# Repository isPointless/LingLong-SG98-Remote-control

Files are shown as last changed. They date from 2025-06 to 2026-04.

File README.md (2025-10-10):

# LingLong SG98 Remote control
A remote control PCB & software to control a grinder with a servo motor.
Currently being built for Linglong SG98 using RT and JMC servo drive.

#### How to use
Aquire a PCB (order through JLCPCB with the provided files or buy a readymade one). and wire it up correctly.
Install Visual Studio code, install the PlatformIO extension. Clone this repo.

Make sure to (un)comment the proper drive type in definitions.
Uploading to ESP32 through USB-C. Make sure +24v is not present. If necessary short press EN while holding BOOT0 button for uploading.
If flash error in final install, plugging in the USB C shortly after pressing "Upload" will make it work.

#### BOM
- ESP32 PCB board + 90 degree 2.54 pins
- 1.69" round corner SPI color display + 2.54 female header
- 19mm ultra short throw momentary button with 3-5V LED.
- M12 4 pin female connector
- KCD1 SPST switch
- 3D printed box, including 4xM3x5Wx4L heat inserts and 2x m3*8 countersunk screw and m3*6 non-countersunk screw.
- A knob for the rotary encoder to your choosing.

-

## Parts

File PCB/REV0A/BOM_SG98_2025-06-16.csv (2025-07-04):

Designator | Footprint | Quantity | Manufacturer Part | Manufacturer | Supplier | Supplier Part | Price
C14,C15 | C0603 | 2 | CL05B104KO5NNNC | SAMSUNG | LCSC | C21122 | 0.004
SW_GND_LED-_3V3 | HDR-TH_4P-P2.54-V-M_1 | 1 |  |  | LCSC
R27 | R1206 | 1 | 1206W4F1000T5E | UNI-ROYAL(厚声) | LCSC | C17901 | 0.003
R3,R4 | R0603 | 2 | 0603WAF6800T5E | UNI-ROYAL(厚声) | LCSC | C23228 | 0.001
C11 | C0603 | 1 |  |  | LCSC | C14663 | 0.003
C12,C19 | C0603 | 2 | CL10C100JB8NNNC | SAMSUNG(三星) | LCSC | C1634 | 0.005
C2,C10 | C1206 | 2 | CL31A106KBHNNNE | SAMSUNG(三星) | LCSC | C13585 | 0.034
R24,R26 | R0603 | 2 | 0603WAF1004T5E | UNI-ROYAL(厚声) | LCSC | C22935 | 0.001
EX_SPI | HDR-TH_6P-P2.54-V-M-A | 1 |  |  | LCSC
EN,GPIO0 | SW-SMD_L3.9-W3.0-P4.45 | 2 | TS-1088-AR02016 | XUNPU(讯普) | LCSC | C720477 | 0.043
R20 | R0603 | 1 | 0402WGF2702TCE | UniOhm | LCSC | C22967 | 0.001
RS485 | TERMINAL_BLOCK_3P_5 | 1
UART | HDR-TH_3P-P2.54-V-M-3 | 1
R6,R7,R16,R25 | R0603 | 4 | 0603WAF2702T5E | UNI-ROYAL(厚声) | LCSC | C22967 | 0.001
R2,R8,R13,R17,R18,R21 | R0603 | 6 | 0603WAF1002T5E | UNI-ROYAL(厚声) | LCSC | C25804 | 0.001
GPIO2 | LED0805-R-RD | 1 | KT-0805黄灯 | KENTO | LCSC | C2296 | 0.012
L1 | SM/L_LPS6235-153MRC | 1 | ? | LPS6235-153MRC | LCSC | C3033031 | 1.562
24V-IN | TERMINALBLOCK:TERMINALBLOCK_BORNIER-2_P5.08MM | 1 |  |  | LCSC
C1,C7,C8,C13,C16,C17,C18,C20,C21,C22 | C0603 | 10 | CC0603KRX7R9BB104 | YAGEO(国巨) | LCSC | C14663 | 0.003
C3,C4,C5 | C0603 | 3 | CL10A106KP8NNNC | SAMSUNG(三星) | LCSC | C19702 | 0.006
C6,C9 | C0603 | 2 | CL10A105KB8NNNC | SAMSUNG(三星) | LCSC | C15849 | 0.005
EX_I2C | HDR-TH_4P-P2.54-V-M_1 | 1 |  |  | LCSC
D2 | SOT-23-6_L2.9-W1.6-P0.95-LS2.8-BR | 1 | USBLC6-2SC6 | STMicroelectronics | LCSC | C7519 | 0.11
D4 | SOT-23(SOT-23-3) | 1 |  | ElecSuper |  | C5180294 | 0.031
F1,F2 | F1812 | 2 | SMD1812P050TF | RUILON(瑞隆源) | LCSC | C12558 | 0.09
L3 | FILTER-SMD_4P-L9.0-W6.0_B82790 | 1 | B82793S0513N201 | TDK | LCSC | C97047 | 0.575
POW1 | LED0603-RD | 1 | KT-0603R | KENTO | LCSC | C2286 | 0.006
Q1 | SOT-23-3_L2.9-W1.3-P1.90-LS2.4-BR | 1 | SS8050(RANGE:200-350) | CJ(江苏长电/长晶) | LCSC | C2150 | 0.013
R1 | R0603 | 1 | 0603WAF3162T5E | UNI-ROYAL(厚声) | LCSC | C25967 | 0.001
R5 | R0603 | 1 | 0603WAF1003T5E | UNI-ROYAL(厚声) | LCSC | C25803 | 0.001
R9,R10,R23 | R0603 | 3 | 0603WAF1001T5E | UNI-ROYAL(厚声) | LCSC | C21190 | 0.001
R11,R12 | R0603 | 2 | 0603WAF5101T5E | UNI-ROYAL(厚声) | LCSC | C23186 | 0.001
R15 | R0603 | 1 | 0603WAF5102T5E | UNI-ROYAL(厚声) | LCSC | C23196 | 0.001
R19,R22 | R0603 | 2 | 0603WAF4700T5E | UNI-ROYAL(厚声) | LCSC | C23179 | 0.001
R14 | R1206 | 1 | 1206W4F1200T5E | UNI-ROYAL(厚声) | LCSC | C17909 | 0.003
SPI_DISPLAY | HDR_TH_8P | 1
SW3 | SW-TH_EC11E15244G1 | 1 | EC11E15244G1 | ALPS Electric | LCSC | C370970 | 2.1
U1 | XDFN-4_L1.0-W1.0-P0.65-BL-EP | 1 | NCP167BMX330TBG | onsemi(安森美) | LCSC | C892227 | 0.428
U2 | MSOP-8 | 1 | MCP16311-E/MS | MICROCHIP | LCSC | C627024 | 1.402
U6 | SOIC-8 | 1 | MAX3485ESA+ | Maxim Integrated | LCSC | C18148 | 1.573
U18 | WIFIM-SMD_ESP32-S3-WROOM-1-N8-NO-VIAS | 1 | ESP32-S3-WROOM-1-N8 | ESPRESSIF(乐鑫) | LCSC | C2913198 | 5.05
USBC1 | USB-C_SMD-TYPE-C-31-M-12 | 1 | TYPE-C-31-M-12 | 韩国韩荣 | LCSC | C165948 | 0.173

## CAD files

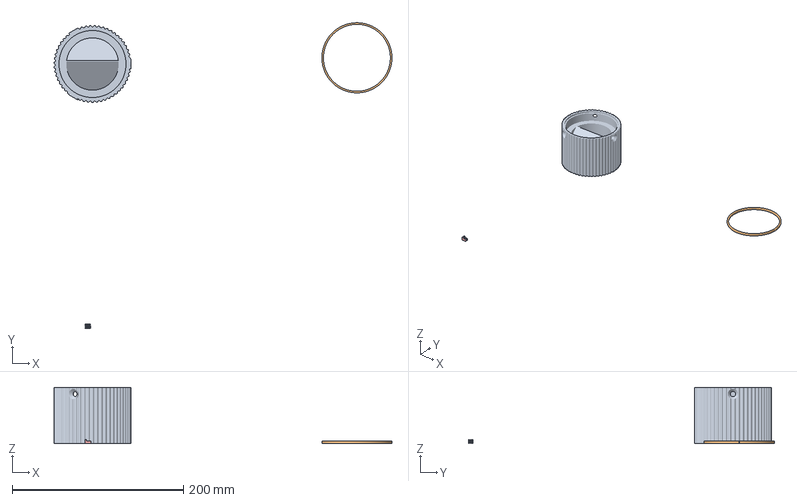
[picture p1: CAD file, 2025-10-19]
3DP parts/Hopper+V2+3mf.3mf
395.0 x 357.1 x 66.0 mm
Hopper V2.stl
Dial indicator V3 Ring.stl
Dial indicator V3.stl x 3

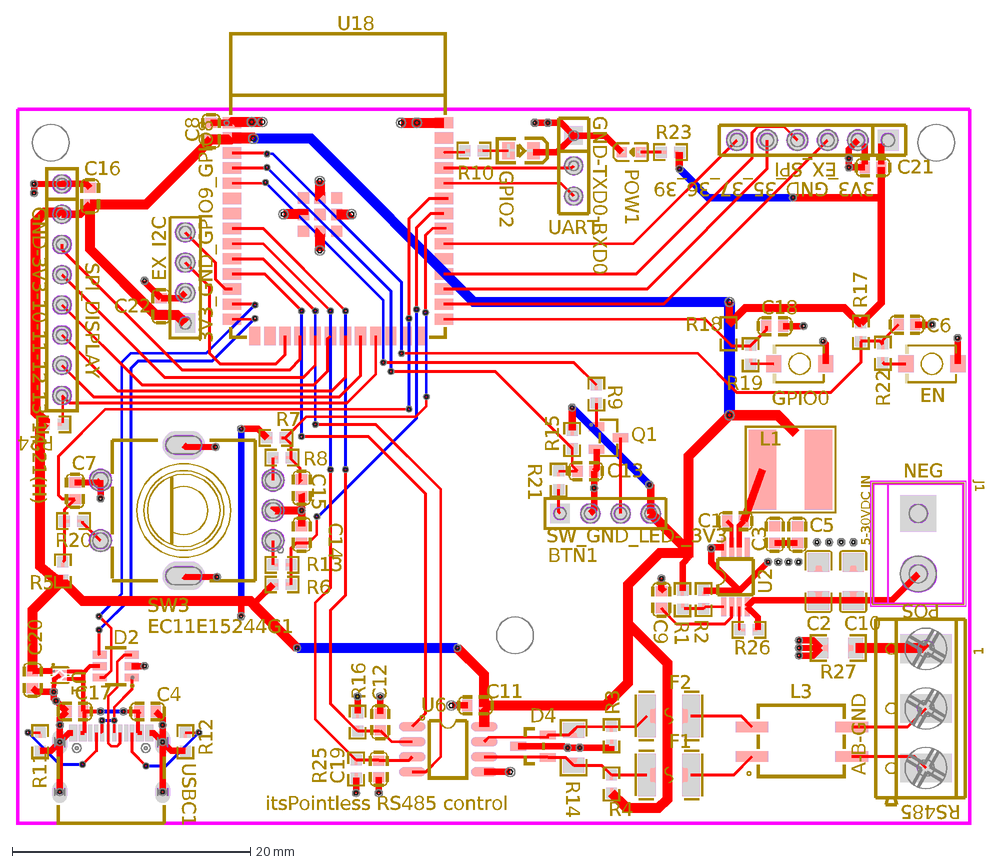
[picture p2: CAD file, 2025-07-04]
PCB/REV0A/PCB_SG98_2025-06-18.dxf
3V3_GND_35_37_36_39
GND-TXD0-RXD0
POS
NEG
A-B-GND
RS485
GND-3V3-10-11-12-13-14-21(H)
itsPointless RS485 control
BTN1
3V3_GND_GPIO9_GPIO8
C14
C15
SW_GND_LED-_3V3
R27
R3
R4
C11
C12
C19
C2
C10
R24
R26
EX_SPI
EN
GPIO0
R20
1
UART
R6
R7
R8
R13
GPIO2
L1
J1
5-30VDC IN
C1
C3
C4
C5
C6
C7
C8
C9
C13
C16
C17
C18
C20
C21
C22
EX_I2C
D2
D4
F1
F2
L3
POW1
Q1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

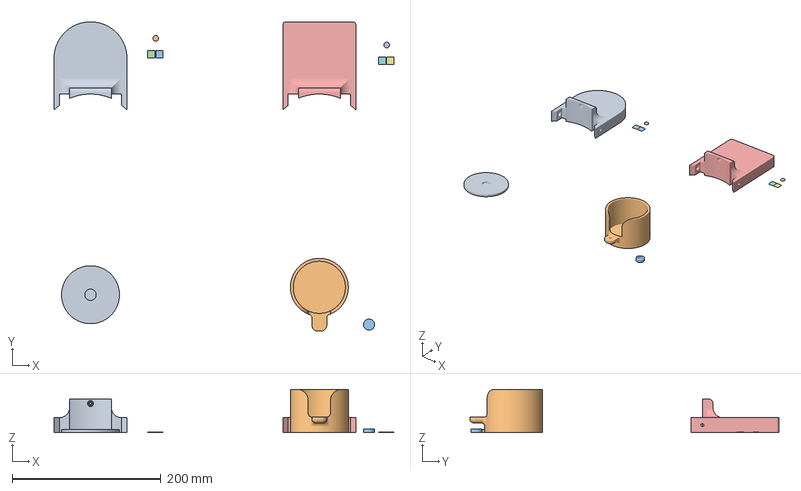
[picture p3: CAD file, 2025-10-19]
3DP parts/Cup+holder+V2++3mf.3mf
456.4 x 415.3 x 58.0 mm
Cup Holder V2 Base.stl
Anti scratch 2.stl x 2
Anti scratch.stl x 4
Cup Holder V2 Base rectangular.stl
Magnet_plate.stl
PF_Holder.stl
PF_Holder_adj_srew.stl

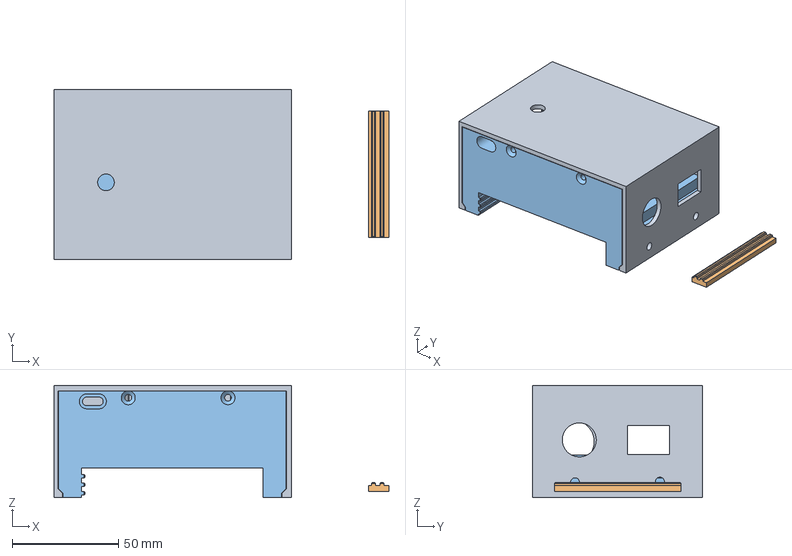
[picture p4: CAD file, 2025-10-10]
3DP parts/LL SideBox V5 RT v0.3mf
157.9 x 80.0 x 52.8 mm
Clamp

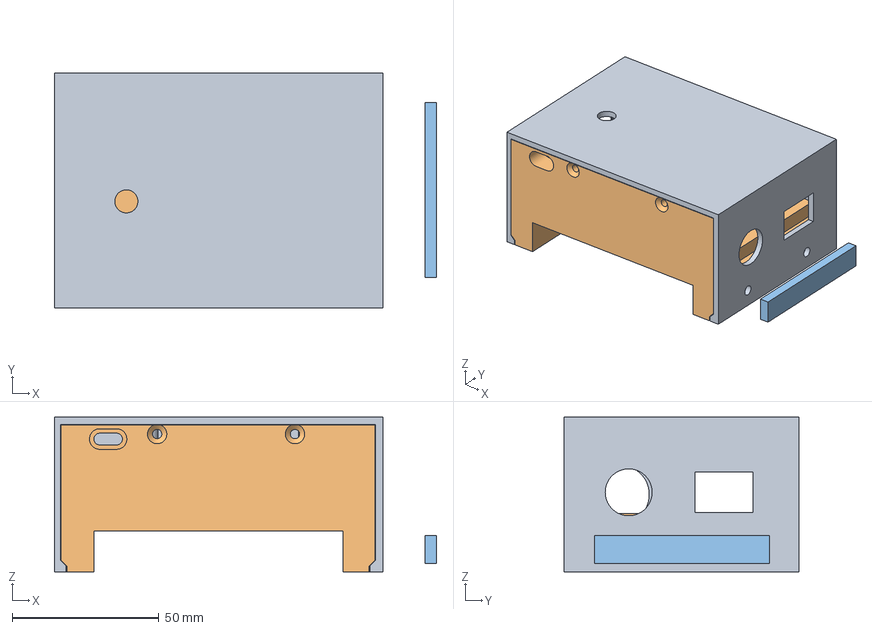
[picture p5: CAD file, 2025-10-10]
3DP parts/LL SideBox V5 JMC v0.3mf
130.2 x 80.0 x 52.8 mm
Clamp
Insert

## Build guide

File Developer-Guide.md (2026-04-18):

# LingLong SG98 Remote Control Developer Guide

## Purpose

This document explains the design, runtime workflow, and motor-control protocol used by the LingLong SG98 remote control project.

It is written for new contributors who need to:

- build and flash the firmware
- understand how the UI and state machine work
- trace how the ESP32 talks to the servo drive
- understand how grind-by-weight works
- know where to make changes safely

This guide is based on the current source tree in this repository.

## What This Project Is

This project is an ESP32-S3 based front-panel controller for a grinder. It is not a desktop application and it does not generate hobby-servo PWM.

The controller does five main jobs:

1. Reads the front-panel controls:
   - start button
   - rotary encoder
   - encoder push button
2. Draws the local UI on a small SPI display.
3. Talks to an industrial servo drive over RS-485.
4. Optionally connects to a BLE scale for grind-by-weight mode.
5. Stores settings and calibration data in ESP32 non-volatile storage.

At a high level, the firmware takes user intent such as "grind at 1000 RPM" or "grind to 18.0 g", converts that into `motor_setRPM`, then the motor-control layer translates that into drive register writes over RS-485.

## Current Build Configuration

The active drive selection is in `src/definitions.h`.

Current source tree:

- `JMC_DRIVE` is disabled
- `RT_DRIVE` is enabled

That means the current firmware build uses the RT motor-control implementation by default.

## Protocol References Used In This Guide

The protocol explanations in this guide come from both the firmware source and the vendor manuals already stored in `Documentation/`.

The most relevant protocol references are:

- `Documentation/JAND-D 15002 Servo drive.pdf`
  - JMC RS-485 / Modbus framing overview
  - especially PDF pages 173-177
- `Documentation/JMC Manual RU.pdf`
  - JMC object dictionary and CiA402 state-machine semantics
  - especially PDF pages 434, 450, 467-478
- `Documentation/RT RS RS485 Series Servo User Manual V4.0.pdf`
  - RT RS-485 / Modbus framing
  - torque-mode parameter meanings
  - monitor parameter meanings
  - especially PDF pages 64-73 and 140-147

When this guide says a manual "defines" something, that comes from those PDFs.
When this guide says "the firmware appears to" or "inference", that comes from matching the source code to the manual terminology and register/object IDs.

## Repository Layout

### Main firmware files

- `src/main.cpp`
  - boot flow
  - top-level loop
  - purge logic
  - sleep logic
- `src/main.h`
  - global states
  - menu enums
  - shared globals
- `src/definitions.h`
  - board pins
  - timing constants
  - build defaults
  - drive selection

### UI and persistence

- `src/io.cpp`
  - button and encoder handling
  - state transitions
  - menu navigation
  - front LED behavior
- `src/display.cpp`
  - display initialization
  - screen drawing
  - error overlay
- `src/pdata.cpp`
  - persistent settings
  - calibration storage
  - saved scale identity

### Scale and motor control

- `src/gbw.cpp`
  - BLE scale management
  - grind-by-weight shot tracking
  - prediction and learning
- `src/comm.cpp`
  - RS-485 transport
  - Modbus-RTU-style framing
  - CRC handling
- `src/motorcontrol_jmc.cpp`
  - JMC drive initialization and runtime control
- `src/motorcontrol_rt.cpp`
  - RT drive initialization and runtime control

### Hardware and reference material

- `Documentation/`
  - vendor manuals
  - mechanical references
- `PCB/`
  - board production files
- `3DP parts/`
  - enclosure parts

## Hardware Overview

The controller appears to be built around an ESP32-S3 Feather-compatible board and a small SPI TFT display.

### Pin map

From `src/definitions.h`:

- RS-485
  - RX: GPIO 18
  - TX: GPIO 17
  - RE: GPIO 15
  - DE: GPIO 16
- User input
  - start button: GPIO 4
  - start button LED: GPIO 5
  - encoder button: GPIO 42
  - encoder A: GPIO 41
  - encoder B: GPIO 40
- Display
  - SCL: GPIO 10
  - SDA/MOSI: GPIO 11
  - RST: GPIO 12
  - DC: GPIO 13
  - CS: GPIO 14
  - backlight: GPIO 21

### Communication links

There are two separate serial paths in this project:

- USB serial
  - used for logs and debugging
  - `Serial.begin(115200)`
- RS-485 serial
  - used for motor drive control
  - `Serial2.begin(9600, SERIAL_8N1, RS485_RXD, RS485_TXD)`

## Build and Flash Workflow

### Tools

The project uses PlatformIO with the Arduino framework.

Relevant dependencies in `platformio.ini`:

- `JC_Button`
- `ESP32Encoder`
- `Adafruit GFX Library`
- `Adafruit-ST7735-Library` from GitHub
- `ESP32Arduino-BLEScale` from GitHub

### Typical developer workflow

1. Open the repository root in VS Code.
2. Make sure PlatformIO is installed.
3. Check `src/definitions.h` and confirm the correct drive type is enabled.
4. Build.
5. Flash over USB-C.
6. Open the serial monitor if needed.

### Safety note for flashing

The project README explicitly warns not to flash with the main `+24V` supply connected. Use USB-C only during firmware upload.

## Runtime Architecture

The firmware is organized around:

- one Arduino main loop
- one FreeRTOS task for the BLE scale
- shared global state

### Boot flow

`setup()` does the following:

1. Starts USB serial logging.
2. Creates `scaleMutex`.
3. Restores GPIO state if waking from deep sleep.
4. Initializes persistent storage.
5. Either loads saved settings or writes defaults on first boot.
6. Starts the background scale task on core 0.
7. Initializes display, inputs, comms, motor control, and watchdog.

### Main loop order

The top-level loop order is important:

1. `doVitals()`
2. `do_comm()`
3. `do_io()`
4. `sleepTimeCheck()`
5. `update_display()`
6. state-specific action

That means:

- motor comms are serviced continuously
- user input can immediately change `state` or `motor_setRPM`
- the display reflects the newest state and feedback

### Background scale task

The scale task runs `gbwVitals()` every 10 ms.

That task is responsible for:

- BLE connection management
- receiving new scale weight values
- tracking the currently connected scale name and MAC
- deciding when the firmware should attempt to connect or maintain the link

The main loop does not directly own BLE operations. It only consumes the resulting shared data such as:

- `currentWeight`
- `scaleStatus`
- `scale_name`
- `scale_mac`

## State Machine

The top-level states are:

- `SLEEPING`
- `IDLE`
- `IDLE_GBW`
- `GRINDING`
- `PURGING`
- `GRINDING_GBW`
- `MENU1`
- `MENU2`
- `MENU3`
- `CALIBRATING`

### `IDLE`

Purpose:

- manual RPM mode

Behavior:

- encoder changes `setRPM`
- start button enters `GRINDING`
- short encoder press opens `MENU1`
- long encoder press switches to `IDLE_GBW`
- last RPM is stored after inactivity

### `IDLE_GBW`

Purpose:

- grind-by-weight mode while idle

Behavior:

- encoder changes `setWeight` in mg
- start button enters `GRINDING_GBW`
- short encoder press opens `MENU1`
- long encoder press switches back to `IDLE`
- last target weight is stored after inactivity

### `GRINDING`

Purpose:

- manual motor run

Behavior:

- motor target follows `setRPM`
- encoder can still adjust RPM while grinding
- start button stops grinding
- if `Purge /w button` is enabled, that stop enters `PURGING`
- otherwise it returns to `IDLE`
- encoder button stops immediately and returns to `IDLE`

### `PURGING`

Purpose:

- clear retained grounds after grind completion or manual request

Behavior:

- optional zero-RPM delay
- forward purge phase
- optional pause
- optional reverse purge phase
- then return to `IDLE`

### `GRINDING_GBW`

Purpose:

- automatic weight-based grinding

Behavior:

- taring if needed
- delayed start
- normal grind RPM
- optional slow phase near target
- prediction-based stop
- short learning phase
- return to `IDLE_GBW`

### Menu states

Purpose:

- view and edit settings

Behavior:

- encoder scrolls menu entries
- encoder press enters or confirms a setting
- start button backs out or cancels the edit

### `CALIBRATING`

Purpose:

- measure grinder torque baseline across RPM points

Behavior:

- motor runs through many RPM steps
- torque is averaged at each step
- results are written to persistent storage

### `SLEEPING`

Purpose:

- deep sleep for inactivity reduction

Behavior:

- watchdog is disabled
- motor is stopped
- display is turned off
- drive is put into a lower-power state
- wake is configured on the start button

## Menu Design

The menu system is data-driven. Menu items are defined in `src/main.cpp` using `menuEntry` arrays.

Each menu entry contains:

- display name
- current value
- min and max
- step scalar
- preference key
- unit string

### Menu 1: general

JMC build currently exposes:

- exit menu
- purge settings
- GbW settings
- sleep time
- display brightness
- LED brightness
- invert scrolling
- max RPM
- min RPM
- motor torque
- motor ramp
- calibrate
- reset default

### Menu 2: purge

- auto purge enable
- purge on button stop
- forward purge RPM
- reverse purge RPM
- purge delay
- purge duration
- zero-RPM delay before purge
- stabilize time before torque detection
- frame thresholds
- high and low torque scalar thresholds
- auto-off time

### Menu 3: grind by weight

- grind RPM
- slow-phase RPM
- slow-phase threshold in mg before target
- start delay
- speed modifier
- stop-time offset
- save scale pairing

## Persistent Data Model

Persistent storage uses the ESP32 `Preferences` API under the namespace `settings`.

### What is stored

- build ID
- manual idle RPM
- GBW target weight
- last idle mode
- all menu values
- calibration array
- saved BLE scale name
- saved BLE scale MAC

### First-boot and migration behavior

On boot, `pdata_init()` compares the stored `build_id` with the current `BUILD_ID`.

If they differ:

- NVS is erased
- defaults are re-written
- the firmware treats the boot as a fresh configuration

This is the project's migration strategy. If you make a settings change that is not backward compatible, bump `BUILD_ID`.

### Persistence write modes

`pdata_write()` is used with numeric modes:

- `0`
  - write all defaults
- `1`
  - write calibration array
- `2`
  - write current menu item
- `3`
  - write current `setRPM` or `setWeight`
- `4`
  - write learned GBW parameters
- `5`
  - write current idle mode
- `6`
  - clear saved scale
- `7`
  - save current scale
- `8`
  - force reset on next boot by changing `build_id`

## Display Design

The UI is full-screen and state-driven. It does not rebuild the whole screen every loop. Instead it:

- tracks the last rendered screen
- tracks previously rendered values
- redraws only when data changes

### Screen types

- manual idle screen
- GBW idle screen
- grinding/purging screen
- GBW grinding screen
- calibrating screen
- menu list screen
- menu value screen
- error overlay

### Display behavior

- refresh is capped by `DISP_REFRESH_RATE`
- `disp_updateRequired` forces refreshes when data changes
- `newData` from the motor also triggers redraw
- the display dims after long inactivity

### What the display shows

Manual idle:

- target RPM
- drive connection state
- purge enabled state

GBW idle:

- target weight
- live scale weight
- drive connection state
- scale connection state

Grinding:

- actual motor RPM
- live torque gauge
- drive state
- purge state

GBW grinding:

- commanded RPM
- current weight
- drive state
- scale state

Calibration:

- live RPM
- live torque reading
- connection state
- progress counter

### Error overlay

Errors are shown as a red overlay on idle screens. Non-fatal errors above 100 auto-clear after 5 seconds.

## Input Handling

The UI uses:

- `JC_Button` for button edge handling
- `ESP32Encoder` for rotary input

Important behavior:

- actions trigger on button release, not on initial press
- long-press detection is used only on the encoder button
- encoder movement updates `lastActivity`
- button release updates `lastActivity`

The front LED is state-driven and supports:

- off
- solid on
- slow flash
- fast flash
- fastest flash
- breathing/fade
- direct PWM percentage

## Communication Stack

The motor communication stack has two layers:

1. a generic RS-485 transport in `src/comm.cpp`
2. a drive-specific protocol in `src/motorcontrol_jmc.cpp` or `src/motorcontrol_rt.cpp`

### What the manuals confirm

The serial framing used by this project matches the Modbus RTU descriptions in:

- `Documentation/JAND-D 15002 Servo drive.pdf`, PDF pages 173-177
- `Documentation/RT RS RS485 Series Servo User Manual V4.0.pdf`, PDF pages 140-147

Those manuals explicitly describe:

- master/slave communication
- function codes `0x03`, `0x06`, and `0x10`
- big-endian 16-bit register data
- CRC16 with polynomial `0xA001`
- CRC low byte first, high byte last
- an idle gap of at least 3.5 character times between frames

That aligns closely with the implementation in `src/comm.cpp`.

### Physical and link settings

Current settings:

- bus type: half-duplex RS-485
- UART: `Serial2`
- baud rate: `9600`
- format: `8N1`
- slave address: `0x01`

Important manual note:

- the RT manual lists the default RS-485 settings as axis address `1`, `115200 bps`, and `8N1`
- the JMC Modbus section also describes RS-485 operation up to `115200`
- this firmware is hard-coded to `9600 8N1`

So for this project to communicate successfully, the attached drive must already be configured to match the firmware, not the vendor default.

### Direction control

The ESP controls RS-485 direction with:

- `RS485DE`
- `RS485RE`

Transmit:

- DE high
- RE high

Receive:

- DE low
- RE low

The code inserts short `delayMicroseconds(500)` delays before and after the transmit flush.

### Frame types

The transport supports standard Modbus-RTU-style register access:

- `0x03`
  - read holding registers
- `0x06`
  - write single register
- `0x10`
  - write multiple registers

### Request formats

Read holding registers:

```text
[slave][0x03][addr_hi][addr_lo][count_hi][count_lo][crc_lo][crc_hi]
```

Write single register:

```text
[slave][0x06][addr_hi][addr_lo][value_hi][value_lo][crc_lo][crc_hi]
```

Write multiple registers:

```text
[slave][0x10][start_hi][start_lo][count_hi][count_lo][byte_count][data...][crc_lo][crc_hi]
```

The RT manual's examples on PDF pages 142-145 and the JMC Modbus manual pages 175-177 use this same structure.

### CRC

CRC is standard Modbus CRC16:

- initial value: `0xFFFF`
- polynomial: `0xA001`
- low byte transmitted first

The RT manual even prints the CRC reference function in its communication chapter on PDF page 146, and it matches the algorithm implemented in `src/comm.cpp`.

### Register numbering conventions from the manuals

Both vendor manuals describe a simple relationship between parameter numbers and Modbus register addresses:

- JMC Modbus manual example:
  - `p03-09` maps to decimal register `309`
- RT manual example:
  - `P08.02` maps to decimal register `802`

This matters because many of the register numbers used by the firmware are not random.

For the RT path especially, several code-level register addresses clearly match the manual's decimalized parameter numbering:

- `503` -> `P05.03`
- `514` -> `P05.14`
- `515` -> `P05.15`
- `1300` -> `P13.00`
- `1301` -> `P13.01`
- `1303` -> `P13.03`

### Transport timing

Key timing constants from `src/definitions.h`:

- `COMM_DELAY_SEND = 60 ms`
- `COMM_DELAY_RECEIVE = 50 ms`
- `COMMINTERVAL = 60 ms`
- `COMM_DELAY_IDLE = 1000 ms`

Behavior:

- when idle, the firmware polls more slowly
- while active grinding is in progress, it polls much faster

### Health tracking

`commCounter` is the main transport-health metric.

- incremented whenever a request is sent
- decremented whenever a valid response is parsed

If it grows too large, the firmware treats the bus as unhealthy and stops the motor.

### Error responses

If the drive returns a 5-byte exception/error frame:

- the firmware stores the drive error code in `errorCode`
- it sets application error `3`
- the display shows "Drive fault"

## Motor Control Abstraction

The rest of the application does not send raw serial frames directly. Instead it uses shared motor variables:

- `motor_setRPM`
- `motor_currentRPM`
- `motor_currentTorque`
- `commStatus`
- `currentStatus`
- `newData`

This separation is important:

- UI and application logic write desired intent into `motor_setRPM`
- the drive layer decides what register sequence is needed to realize that intent

That makes the top-level application mostly drive-agnostic.

## JMC Drive Protocol

This is the active implementation in the current source tree.

### Vendor manual basis

The JMC protocol explanation in this section uses two different JMC documents for two different layers:

- `Documentation/JAND-D 15002 Servo drive.pdf`
  - for the serial Modbus RTU transport format
- `Documentation/JMC Manual RU.pdf`
  - for the meaning of objects such as `0x6040`, `0x6041`, `0x606C`, and `0x6077`

Important inference:

- the JMC object semantics in the manual are described in the EtherCAT / CoE / CiA402 chapter
- this firmware does not speak EtherCAT
- however, the object IDs and state values line up with what the firmware reads and writes over RS-485

So the best working model is:

- transport layer
  - Modbus RTU over RS-485
- object semantics
  - CiA402-style JMC object dictionary

That inference is based on the code plus the manual, not on a single manual sentence that says exactly that.

### High-level model

The JMC path is torque-mode based.

The firmware does not simply write "run at RPM". Instead it configures:

- torque control mode
- torque command source
- speed limit source
- torque target
- speed limit
- control word

The drive then enforces the speed limit while running in torque mode.

The JMC manual's communication chapter states that its object dictionary follows CiA402 / CiA301 conventions, and the objects the firmware uses match that model:

- `0x6040`
  - control word
- `0x6041`
  - status word
- `0x606C`
  - actual speed
- `0x6077`
  - actual torque

### Initialization sequence

When disconnected, the firmware attempts to establish first contact by writing:

- `0x6040 = 1`

If that succeeds, it reads `0x1010` and checks for the magic value:

- word 0: `0x6576`
- word 1: `0x6173`

This is the string `"Save"` split across two 16-bit registers.

If that magic value is not present, the firmware treats the drive as not yet configured for this project and writes the required parameters.

This `0x1010` save-marker behavior is project-specific firmware logic. It is not one of the standard CiA402 objects discussed in the manual section used here.

### JMC register roles used by the firmware

Core state and feedback:

- `0x6040`
  - control word
- `0x6041`
  - status word
- `0x606C`
  - actual velocity
- `0x6077`
  - actual torque

Manual-backed meanings:

- `0x6040`
  - control word used to enable output, stop, start, and fault-reset state transitions
- `0x6041`
  - read-only status word reflecting the current drive state
- `0x606C`
  - actual speed in `r/min`
- `0x6077`
  - actual torque in `‰` of rated torque

Configuration and persistence:

- `0x1010`
  - save marker used by this firmware
- `0x2101`
  - mode, set to torque control
- `0x2102`
  - rigidity source selection
- `0x2103`
  - rigidity amount
- `0x2121`
  - quick-stop torque
- `0x2203`
  - velocity feed-forward gain
- `0x2204`
  - velocity feed-forward filter or related parameter

Torque-mode command path:

- `0x2500`
  - torque command source
- `0x2501`
  - speed limit source
- `0x2502`
  - speed limit setpoint
- `0x2503`
  - torque setpoint
- `0x2510`
  - forward torque limit
- `0x2511`
  - reverse torque limit

### JMC initialization values written by the firmware

- `0x2101 = 2`
  - torque control mode
- `0x2102 = 1`
  - semi-auto rigidity source
- `0x2103 = Menu1[SETMOTORRAMP]`
  - rigidity/ramp level chosen in menu
- `0x2121 = 30`
  - quick-stop torque
- `0x2203 = 0`
- `0x2204 = 2000`
- `0x2500 = 1`
  - torque command source
- `0x2501 = 1`
  - speed limit source
- `0x2502 = 0`
- `0x2503 = 0`
- `0x2510 = +torque_limit`
- `0x2511 = -torque_limit`

### Runtime command sequence

The JMC manual's control-word table shows these documented CiA402-style transition words:

- `0x0006`
  - shutdown / holding-brake state
- `0x0007`
  - output voltage / unlocked
- `0x000F`
  - power-on enable / operation enable
- `0x0080`
  - fault reset

That is useful when comparing firmware behavior to the manual.

#### Stop

When `motor_setRPM == 0`, the firmware drives the JMC controller toward:

- `0x2503 = 0`
  - zero torque
- `0x2502 = 0`
  - zero speed limit
- `0x6040 = 3`
  - servo disable / non-enabled state used by this project

Note:

- `0x0003` is a real value used by the firmware and appears to work in practice
- it is not one of the explicit state-transition examples printed in the extracted JMC manual table
- treat it as project-proven behavior rather than a value directly documented in the cited table

#### Forward rotation

When `motor_setRPM > 0`, the firmware drives the controller toward:

- `0x2502 = motor_setRPM`
- `0x6040 = 0x000F`
  - enable operation
- `0x2503 = +Menu1[SETMOTORTORQUE]`

Interpretation:

- set the speed ceiling
- enable the servo
- command positive torque

#### Reverse rotation

When `motor_setRPM < 0`, the firmware drives the controller toward:

- `0x2502 = abs(motor_setRPM)`
- `0x6040 = 0x000F`
- `0x2503 = -Menu1[SETMOTORTORQUE]`

Interpretation:

- same speed ceiling mechanism
- same enable word
- negative torque commands reverse direction

### Status polling

Once command registers are in the expected state, the firmware alternates reads of:

- `0x6041`
  - status word
- `0x606C`
  - velocity
- `0x6077`
  - torque

Manual-backed units:

- `0x606C`
  - rpm
- `0x6077`
  - per-mille of rated torque, not raw physical torque in N·m

That is why the code's "percent" style calculations are only an application-level approximation.
The display and purge logic are using the returned value as a convenient relative load metric.

### JMC status word decoding

The firmware masks the JMC status word with `0x006F` and maps the result into:

- switch on disabled
- ready to switch on
- switched on
- operation enabled
- fault
- fault reaction active
- quick stop active

Those values match the JMC manual's status-word state table:

- `0x0021`
  - ready for operation
- `0x0023`
  - can start / switched on
- `0x0027`
  - run enable / operation enabled
- `0x0007`
  - quick stop effective
- `0x0008`
  - fault state
- `0x000F`
  - fault operation / fault reaction active

Those are then converted to application-level states:

- `MOTOR_NOT_READY`
- `MOTOR_READY`
- `MOTOR_ENABLED`
- `MOTOR_FAULT`

### Example JMC frames

Enable operation:

```text
01 06 60 40 00 0F CRClo CRChi
```

Set speed limit to 1000 RPM:

```text
01 06 25 02 03 E8 CRClo CRChi
```

Set torque target to +100:

```text
01 06 25 03 00 64 CRClo CRChi
```

Read status word:

```text
01 03 60 41 00 01 CRClo CRChi
```

Read torque:

```text
01 03 60 77 00 01 CRClo CRChi
```

### Important JMC design implication

This project is using an industrial servo drive with a register protocol that looks CiA-402-like in parts. It is not sending a hobby-servo pulse train and it is not commanding a standalone BLDC driver directly.

## RT Drive Protocol

The RT implementation uses the same transport but a different register map.

### Vendor manual basis

The RT protocol explanation here combines:

- `Documentation/RT RS RS485 Series Servo User Manual V4.0.pdf`, PDF pages 140-147
  - Modbus RTU framing
- PDF pages 64-73 and 108-109
  - speed-mode / torque-mode parameter meanings
- PDF page 135
  - monitoring parameter meanings

Unlike the JMC section, the RT manual is more clearly parameter-oriented than object-dictionary-oriented.

### High-level model

The RT path uses:

- enable/disable register
- torque register
- separate forward and reverse speed limits
- jog command register

Manual-backed control concepts:

- `P01.00 = 2`
  - torque control mode
- `P05.14`
  - torque-mode forward internal speed limit in rpm
- `P05.15`
  - torque-mode reverse internal speed limit in rpm
- `P05.03`
  - digital-given torque in `0.1%`
- `P05.20`
  - communication-given torque in `0.001%`

Important design observation:

- the firmware does not appear to use the RT manual's dedicated communication-given torque parameter `P05.20`
- instead it writes register `503`, which matches `P05.03`
- so the project is effectively remote-writing the drive's torque setpoint parameter over Modbus, rather than using the manual's separate "communication given torque" path

### RT registers used by the firmware

Command path:

- `201`
  - enable or disable drive
- `503`
  - torque command
- `514`
  - forward speed limit
- `515`
  - reverse speed limit
- `525`
  - jog control
    - `0`
      - stop
    - `1`
      - forward
    - `2`
      - reverse

Status/feedback:

- `1300`
  - running state
- `1301`
  - current RPM
- `1302`
  - another feedback word, currently unused
- `1303`
  - motor torque

The following RT mappings are directly supported by the manual's parameter-number-to-register rule:

- `503`
  - `P05.03`, digital-given torque, unit `0.1%`
- `514`
  - `P05.14`, torque-mode forward internal speed limit, unit rpm
- `515`
  - `P05.15`, torque-mode reverse internal speed limit, unit rpm
- `1300`
  - `P13.00`, servo running status
- `1301`
  - `P13.01`, motor speed, unit rpm
- `1303`
  - `P13.03`, motor torque, unit `0.1%`

Registers `201` and `525` are used by the firmware as drive enable and jog-direction controls, but this documentation pass did not recover their exact manual text. Their runtime meaning is therefore taken from the code path rather than a confirmed extracted page.

### RT initialization

The project currently treats a successful write of:

- `514 = 0`
- `515 = 0`

as proof that communication has been established.

### Runtime command sequence

#### Stop

- write `514, 515 = 0, 0`
- write `525 = 0`
- write `201 = 0`

#### Forward

- write `201 = 1`
- write `503 = torque_limit * 10`
- write `514, 515 = motor_setRPM, 0`
- write `525 = 1`

Why `torque_limit * 10`:

- the UI stores torque as an integer percent
- the RT manual defines `P05.03` in units of `0.1%`
- multiplying by 10 converts firmware percent units into the drive's parameter units

#### Reverse

- write `201 = 1`
- write `503 = -(torque_limit * 10)`
- write `514, 515 = 0, abs(motor_setRPM)`
- write `525 = 2`

Why `514` and `515` are written separately:

- the RT manual defines separate forward and reverse internal speed limits in torque mode
- the firmware uses that directly instead of sending a single signed speed word

### RT polling

The firmware repeatedly reads:

- `1300`
- `1301`
- `1302`
- `1303`

and interprets them as:

- status
- RPM
- unused/ignored feedback
- torque

The RT manual's monitoring-parameter section confirms:

- `P13.00`
  - running status
- `P13.01`
  - actual motor speed in rpm
- `P13.03`
  - actual motor torque in `0.1%`, where `100%` corresponds to rated torque

That matches the code comments and the way the firmware consumes those values.

## Auto Purge Algorithm

The purge system is one of the more project-specific pieces of logic.

### Purpose

The controller wants to detect when beans are no longer passing through normally and then run a purge sequence to clear retained grounds.

### How it works

1. During calibration, the firmware records the normal unloaded or lightly loaded torque profile versus RPM.
2. During a manual grind, it compares live torque against the stored calibrated torque at the current RPM.
3. If torque exceeds a configured percentage threshold for enough consecutive frames, it marks `ready_purge = true`.
4. While grounds are still flowing, `lastActivity` keeps being refreshed.
5. Once flow appears to stop and the configured delay expires, it enters `PURGING`.

### Threshold structure

There are separate purge settings for:

- low RPM
- high RPM

Each has:

- required frame count
- torque scalar percentage

That lets the purge detector behave differently at slow and fast grind speeds.

### Purge sequence structure

The purge routine supports:

- initial delay at zero RPM
- forward purge
- optional reverse purge

The reverse purge is disabled by setting reverse RPM to `0`.

## Grind-by-Weight Design

The GBW system is built around a BLE scale, not a load cell wired into the ESP32.

### Connection model

The background scale task decides whether to connect based on the top-level state:

- in `IDLE_GBW` and `GRINDING_GBW`
  - connect and maintain
- in regular idle, regular grinding, and sleep
  - do not maintain the connection

### Saved pairing

The firmware can store a scale name and MAC address.

When "Save scale" is enabled in Menu 3:

- the current connected scale identity is copied into persistent storage

When it is disabled:

- the stored pairing is removed

### Shot lifecycle

When entering `GRINDING_GBW`, the firmware:

1. resets all shot-tracking state
2. verifies the scale is connected
3. tares if necessary
4. waits for tare stabilization
5. starts shot timing
6. begins motor control after the configured start delay

### Shot sample buffer

The project stores a rolling shot trace in:

- `_shot[300]`

Each element contains:

- time since shot start
- absolute weight in mg

This trace is used for:

- live prediction
- stop point estimation
- post-shot learning

### Prediction

Prediction combines:

- recent actual slope from the last few weight samples
- fallback model using:
  - `SpeedModifier`
  - GBW RPM

The system computes remaining grind time in ms and subtracts the configured offset.

When the predicted remaining time goes below zero:

- the firmware stops the motor

### Slow phase

If enabled:

- the motor runs at normal GBW RPM first
- once current weight crosses `setWeight - GBW_SLOW_MG`
- the firmware switches to `GBW_SLOW_RPM`

This is a simple two-stage feed strategy:

- bulk fill
- controlled finish

### Learning

After a proper shot, the firmware estimates:

- the weight at the moment the motor actually stopped
- the live grind speed near stop
- the shot overshoot

It then uses that to update:

- `GBW_SPEEDMOD`
- `GBW_OFFSET`

but only if the shot passes several sanity checks.

The code rejects obviously bad shots, for example:

- too much overshoot
- impossible offset value
- too-short sample window
- invalid speed estimate

### GBW failure modes

The code explicitly handles:

- no scale connected at start
- scale disconnect during shot
- no grounds detected after 3 seconds

## Calibration System

The calibration system builds the torque baseline used by purge detection.

### Procedure

1. Ensure the drive is connected.
2. Start at the minimum RPM point.
3. Wait a short stabilization period.
4. Average torque samples for a fixed time window.
5. Store the average in `calibrateArray`.
6. Move to the next RPM step.
7. Repeat until done.
8. Save the array to persistent storage.

### Step size

The step size is controlled by:

- `rpm_scalar = 25`

### Why it exists

Without calibration, the purge detector would not know what "normal" torque looks like at each RPM.

## Sleep and Wake Behavior

The firmware supports deep sleep after inactivity.

### Sleep entry

If the user-configured sleep time expires and the controller is not actively grinding:

- `state` becomes `SLEEPING`

The main loop then:

- turns off the LED
- stops the motor
- turns off the display
- asks the drive to sleep if supported
- enables deep sleep

### Wake source

The actual implemented wake source is the start button on GPIO 4.

There are constants for encoder wake pins in `src/definitions.h`, but the current code only configures EXT0 wake on the start button.

## Error Model

Application errors are defined centrally in `src/main.h`.

### Fatal or blocking errors

- `1`
  - could not connect to drive
- `2`
  - drive connection lost
- `3`
  - drive returned error frame
- `4`
  - packet loss / communication discrepancy
- `5`
  - failed to create mutex
- `6`
  - motor stalled
- `7`
  - initial write/configuration failure
- `8`
  - first boot or drive not fully configured yet

### Non-fatal or recoverable errors

- `101`
  - calibration could not start
- `102`
  - calibration cancelled
- `103`
  - stored data load issue
- `104`
  - scale disconnected during GBW
- `105`
  - no grounds detected after 3 seconds
- `106`
  - no scale connected
- `107`
  - drive reboot needed after rigidity change

## Common Development Tasks

### Change a pin or timing constant

Edit:

- `src/definitions.h`

Examples:

- RS-485 timing
- display pinout
- default RPMs
- default purge settings

### Change menu items or defaults

Edit:

- `src/main.h`
  - enums
- `src/main.cpp`
  - `Menu1`, `Menu2`, `Menu3`
- `src/definitions.h`
  - default values if needed

Persistence mostly follows automatically because the menu arrays carry preference keys.

### Change screen layout or text

Edit:

- `src/display.cpp`

### Change encoder or button behavior

Edit:

- `src/io.cpp`

### Change serial transport behavior

Edit:

- `src/comm.cpp`
- `src/comm.h`

Examples:

- baud rate
- timing
- CRC handling
- request/response parsing

### Change drive register protocol

Edit:

- `src/motorcontrol_jmc.cpp`
  - for current build
- `src/motorcontrol_rt.cpp`
  - for RT variant

### Change GBW logic

Edit:

- `src/gbw.cpp`

Examples:

- prediction
- slow phase threshold
- learning logic
- scale connection behavior

### Change what is stored in NVS

Edit:

- `src/pdata.cpp`

If the new storage layout is incompatible with what existing boards already have, bump `BUILD_ID` in `src/definitions.h`.

## Known Quirks and Technical Debt

This section is important for new contributors. A few things in the code are surprising and can waste time if you assume they are cleaner than they are.

### 1. `src/JMC/comm_jmc.cpp` is not active

That file is wrapped in:

```cpp
#ifdef JMC_DRIVE_n
```

Since `JMC_DRIVE_n` is not defined, that file does not build. The active transport for both drive variants is `src/comm.cpp`.

### 2. The "servo protocol" is really industrial drive register control

This project does not command a hobby servo.

What the code calls the servo protocol is:

- RS-485 register reads and writes
- a CiA-402-like JMC register model
- or a custom RT register map

### 3. `default_sleepTime` comment is misleading

The menu labels sleep time in minutes and the sleep check multiplies by `60000`, so this setting behaves as minutes.

### 4. Some constants and comments are stale

Examples:

- comments mention packet-loss thresholds that do not match the actual code
- some wake-pin constants exist but are not used
- some read comments do not exactly match the request sizes

Treat the executable logic as the source of truth, not the comments.

### 5. Calibration array sizing is confusing

`SIZEOFCALIBRATEARRAY` is used as if it were a byte count in some places and an element count in others.

That means any contributor touching calibration storage should review:

- declaration size
- iteration counts
- NVS byte counts

before changing it.

### 6. The drive is expected to be partially configured by firmware

The JMC path writes a firmware-specific save marker and configuration values into the drive. That means the drive is not treated as a fixed black box. The firmware and drive setup are coupled.

## Suggested Onboarding Path for New Contributors

If you are completely new to the project, the best reading order is:

1. `src/definitions.h`
   - know the hardware and defaults
2. `src/main.h`
   - know the states and menus
3. `src/main.cpp`
   - understand the top-level loop
4. `src/io.cpp`
   - understand how user actions change state
5. `src/comm.cpp`
   - understand the transport
6. `src/motorcontrol_jmc.cpp`
   - understand the active motor protocol
7. `src/gbw.cpp`
   - understand the second major feature set
8. `src/display.cpp`
   - understand how the UI reflects system state
9. `src/pdata.cpp`
   - understand persistence and migration

## Quick Mental Model

If you only remember one architectural summary, use this one:

- `setRPM` and `setWeight` are user-facing targets
- `state` chooses which workflow is active
- `motor_setRPM` is the actual command handed to the drive layer
- `do_comm()` turns `motor_setRPM` into drive register traffic
- `motor_currentRPM` and `motor_currentTorque` come back from the drive
- `newData` tells purge and calibration code that fresh torque data arrived
- `gbwVitals()` maintains the BLE scale in the background
- `do_gbw()` uses live weight feedback to decide when to slow and stop
- `pdata_*()` makes settings survive reboots
- `display.cpp` turns all of that into the UI

## Reference Documents

Vendor and hardware references already included in this repository:

- `Documentation/JMC Manual RU.pdf`
- `Documentation/JAND-D 15002 Servo drive.pdf`
- `Documentation/JAND-P28_DB44 Use manual.pdf`
- `Documentation/RT RS RS485 Series Servo User Manual V4.0.pdf`
- `Documentation/Instructions for use.pdf`

Most useful protocol pages:

- `Documentation/JAND-D 15002 Servo drive.pdf`
  - PDF pages 173-177 for Modbus RTU framing examples
- `Documentation/JMC Manual RU.pdf`
  - PDF page 434 for CiA402 / object-dictionary context
  - PDF page 450 for the CiA402 state-machine overview
  - PDF pages 467-470 for `0x6040` and `0x6041`
  - PDF page 475 for `0x606C`
  - PDF page 478 for `0x6077`
- `Documentation/RT RS RS485 Series Servo User Manual V4.0.pdf`
  - PDF pages 64-73 for torque-mode and command-source behavior
  - PDF pages 108-109 for `P05.14`, `P05.15`, and `P05.20`
  - PDF page 135 for `P13.00`, `P13.01`, and `P13.03`
  - PDF pages 140-147 for Modbus RTU framing and CRC

Those documents should be used when:

- confirming exact vendor register semantics
- checking wiring details
- validating alarm meanings
- extending support for drive features not already implemented here

## Final Notes

For new project work:

- use `src/comm.cpp` and the active `motorcontrol_*.cpp` file as protocol truth
- treat `src/definitions.h` as the hardware and behavior configuration root
- bump `BUILD_ID` when changing persisted settings layout
- be careful with calibration storage and timing assumptions
- remember that manual grind, auto purge, and GBW are three different workflows layered on the same motor abstraction

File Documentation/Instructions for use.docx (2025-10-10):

# LL RS485 Grind Controller – Instruction Sheet

⚠️ USE AT YOUR OWN RISK
This is a development project, not a commercial product.
The hardware and firmware are intended for testing and hobbyist experimentation.

## INSTALLATION

1. Turn off servo drive (PSU box)
2. Physically mount the box, using the provided nuts, thumb screws & plastic spacer to clamp it.
3. Remove the wire/connector from the original remote control box, plug it into this box.
4. Turn on drive box and make sure the small box is also turned on (no specific order)

## FIRST STARTUP

The controller comes preloaded with default parameters, tested on the RT version of the LL SG98 grinder.
Be cautious when changing settings — most parameters directly affect how the servo drive operates.

1. The box will show “Please reboot drive” to confirm that it has written the new settings. You will now have to reboot the servo drive (the big PSU box).
2. Press START to verify that the motor spins in the correct direction when in NORMAL mode (not GBW mode).
3. Open Menu 1, find “Calibrate”, and long press SELECT to start the calibration. The calibration process runs automatically and will stop when finished.

## OPERATING MODES

The controller has two primary operating modes:
NORMAL and GBW (Grind-by-Weight).
You can switch between them by long pressing the SELECT button while being in either IDLE mode.

IDLE

When idle in normal mode, the display shows:

- target RPM
- Connection status
- Auto purge setting
- Pressing START will enable the grinder, pressing SELECT shortly will enter the menu.

NORMAL GRINDING MODE

In this mode, the controller automatically detects bean grinding by monitoring motor load.

- After grinding beans (or no interaction occurs for the set time), the grinder will automatically purge
- Pressing SELECT during operation will always stop the motor.
- If “Purge /w button” is enabled, pressing START triggers a purge cycle; otherwise, it will stop the motor.

PURGE FUNCTION

(PURGE SEQUENCE: FREE RUNNING → GRINDING → (delay) → STOP → FORWARD → REVERSE)

Purging helps clear remaining grounds after grinding stops.

Pressing either button will stop the grinder.

You can customize purge behavior under Menu 2 → Purge Settings:

- Enable or disable automatic purge (after grind detection)
- Adjust purge delay and purge duration
- Set forward and reverse purge RPMs (set to 0 to disable this action)
- Enable purge by button press
- Fine-tune purge sensitivity (frames and scalars).

GBW – Grind-by-Weight Mode

In this mode, the controller grinds beans until a target weight is reached, using a connected Bluetooth scale.

⚖️ Recommended scale: Bookoo Themis Mini. (Acaia and Felicita Arc work too)

1. Connect a compatible scale (Bluetooth must be enabled). The controller will automatically pair with scale.
2. Place the scale under your dosing cup and fill the hopper with beans.
3. Select the desired target weight.
4. Press START to begin GBW grinding. The scale will beep once the target is reached.

The controller self-learns over time, improving accuracy automatically.

Note: Coffee ground in GBW mode tends to be slightly finer than in NORMAL mode, due to bean pressure.
Adjust the grinder coarser to combat this. Unfortunately an emptying hopper will change the grind size over time. Keep the hopper partly filled to have the grind size stable.

GbW settings can be customized in the menu.

To exit GbW mode and return to normal operation, long press SELECT.
(This also disconnects the scale.)

MENU

Enter the menu by short-pressing SELECT while in IDLE NORMAL or IDLE GBW mode.

- SELECT → Enter submenu, Enter setting or SAVE when in a setting.
- START → go back without saving changes
- SELECT (long press) → trigger special functions (e.g., calibration)

Menu 1 – Main Menu

No. | Setting | Description
1 | EXIT MENU | Exit and return to the IDLE display
2 | Purge Settings | Opens the purge configuration submenu (Menu 2).
3 | GbW Settings | Opens the grind-by-weight configuration submenu (Menu 3).
4 | Sleep time | Time (min) before the controller enters deep sleep. Set 0 to disable sleep.
5 | Brightness | Adjust display brightness (1–255).
6 | LED max Brightness | Adjust button LED brightness (0–100 %). Set 0 to turn off button LED.
7 | Invert scrolling | Invert menu scroll direction (CW ↔ CCW).
8 | Max RPM | Set maximum motor speed limit.
9 | Min RPM | Set minimum motor speed limit
10 | Motor torque | Adjust motor torque (%)
11 | Motor ramp | Control motor rigidity level (level 0–12). A higher rigidity can cause noise, vibration and fast spin up but will keep a tighter RPM. You will need to reboot the servo drive (big PSU box) to activate the new setting.
12 | Calibrate | Run the auto-purge calibration routine. Long press SELECT to begin.

### Menu 2 – Purge Settings

No. | Setting | Description
1 | BACK | Return to Menu 1.
2 | Auto purge enabled | Enable or disable automatic purge.
3 | Purge /w button | Run a purge when pressing START while the grinding is running.
4 | Purge forward RPM | Forward purge speed (RPM). Set 0 to disable.
5 | Reverse rotation | Reverse purge speed (RPM). Set 0 to disable.
6 | Purge delay | Delay (ms) between end of grind (last bean ground) and purge start.
7 | Purge duration | Duration (ms) of each purge phase
8 | Purge 0 RPM time | Time (ms) motor goes to 0 rpm before purging. 0 = immediately spin up (can cause issues with reverse purge atm)
9 | Purge stabilize time | Stabilization delay after starting or adjusting rpm (ms) before detection triggers.
10 | Purge frames HIGH | Frame count for high-speed (> 500 RPM) detection.
11 | Purge frames LOW | Frame count for low-speed (< 500 RPM) detection.
12 | Purge Scalar HIGH | Sensitivity adjustment (%) for high-speed detection.
13 | Purge Scalar LOW | Sensitivity adjustment (%) for low-speed detection.
14 | Auto off time | Time (s) untill the grinder stops if no grinding is detected.

Menu 3 – GbW Settings (Grind-by-Weight)

No. | Setting | Description
1 | BACK | Return to Menu 1.
2 | GbW RPM | Motor speed (RPM) for main GbW grinding phase.
3 | GbW Slow RPM | RPM used in the final slow approach phase.
4 | GbW Slow Phase t | Duration (ms) of the slow-grind phase, 0 to disable slow phase
5 | Start delay | Delay (ms) after pressing START, preventing false scale reading due to interaction vibrations.
6 | SpeedModifier | Auto-learning multiplier, not recommended to manually adjust. (default: 4500)
7 | Time offset | Auto-learning correction value (ms) (default: 200)
8 | Save scale | Reconnect only to the currently paired scale to prevent unwanted pairing to other scales.

### NOTES

- Use caution when changing max RPM, torque, or ramp settings, as these affect motor load and grinder behavior. Reasonably safe limits have been implemented however use at your own risk.
- I am in no way liable for any issues or harm caused by this project
- Future updates will be communicated over EAF discord
- Currently the release version for JMC changes a setting which makes it no longer work with the original controlbox. To fix this, you’ll need to manually change a parameter on the servo drive, this controller runs the servo in “Torque mode” allowing a torque limit as a safety feature. The original box runs it in “speed mode” which will push the servo into its (very high) limits indefinetely even when something inside the grinder is blocked. This parameter is P01-01 and must be changed from 2 (torque) back to 1 (speed) to have the original remote controlbox working again.

RESALE IN ANY WAY OR FORM IS NOT ALLOWED WITHOUT EXPLICIT WRITTEN PERMISSION

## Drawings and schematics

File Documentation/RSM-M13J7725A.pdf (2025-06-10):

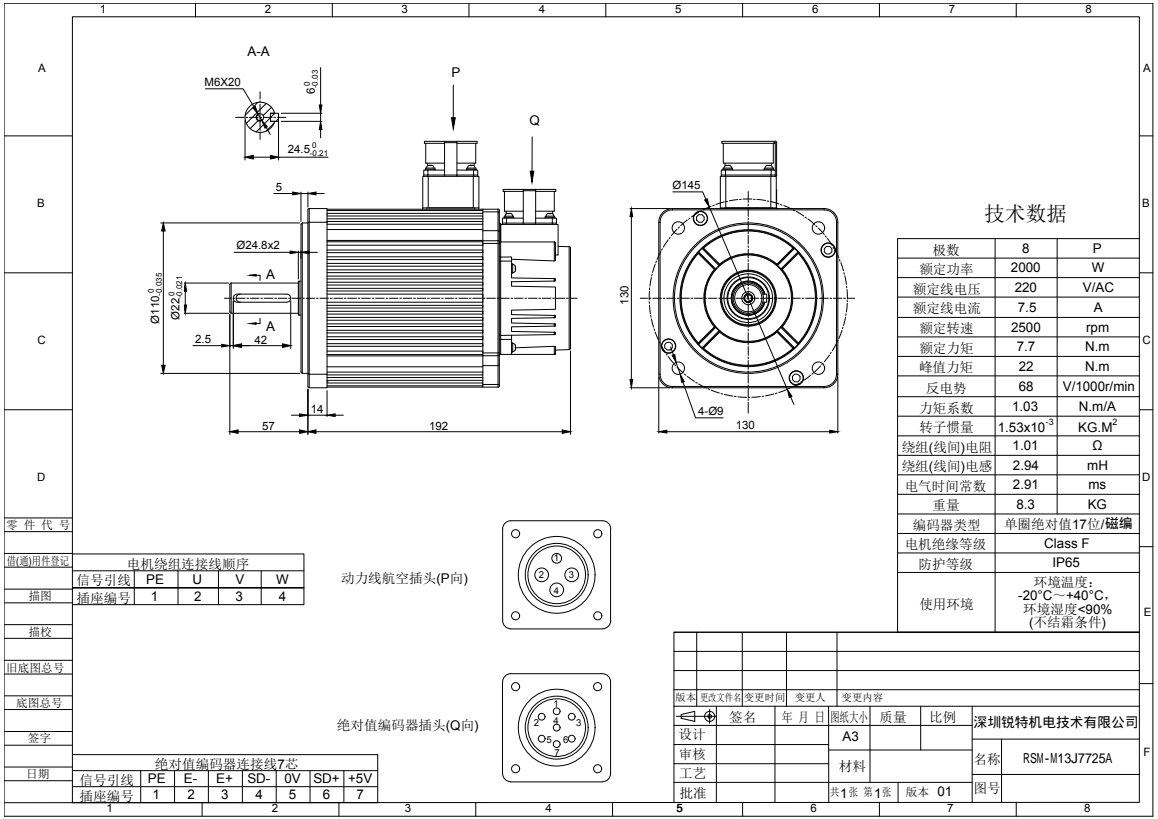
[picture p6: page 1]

极数 | 8 | P
额定功率 | 2000 | W
额定线电压 | 220 | V/AC
额定线电流 | 7.5 | A
额定转速 | 2500 | rpm
额定力矩 | 7.7 | N.m
峰值力矩 | 22 | N.m
反电势 | 68 | V/1000r/min
力矩系数 | 1.03 | N.m/A
转子惯量 | -3 1.53x10 | 2 KG.M
绕组(线间)电阻 | 1.01 | Ω
绕组(线间)电感 | 2.94 | mH
电气时间常数 | 2.91 | ms
重量 | 8.3 | KG
编码器类型 | 单圈绝对值17位/ 磁编
电机绝缘等级 | Class F

版本 | 更改文件名 变更时间 | | 变更人 | 变更内容

签名 | 年 月 日 | 图纸大小 | 质量 | 比例

设计 | | | | A3
审核

信号引线 | PE | E- | E+ | SD- | 0V | SD+ | +5V
插座编号 | 1 | 2 | 3 | 4 | 5 | 6 | 7

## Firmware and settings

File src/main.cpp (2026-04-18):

#include <driver/rtc_io.h>
#include "esp_task_wdt.h"
#include "display.h"
#include "main.h"
#include "gbw.h"
#include "pdata.h"
#include "display.h"
#include "io.h"
#include "comm.h"

#ifdef RT_DRIVE 
#include "motorcontrol_rt.h"
#endif 
#ifdef JMC_DRIVE
#include "motorcontrol_jmc.h"
#endif

States state = IDLE;
int8_t menu1Selected = EXITMENU;
int8_t menu2Selected = RETURN_FROM_PURGE;
int8_t menu3Selected = RETURN_FROM_GBW;
bool enterMenu = false;
bool firstBootFlag = false;

#ifdef JMC_DRIVE
menuEntry Menu1[NUM_MENU1_ITEMS] = {
    {"EXIT MENU", 0, 0, 0, 0, "EXITMENU", ""},                 // 0
    {"Purge Settings", 0, 0, 0, 0, "PURGESETT", ""},           // 1
    {"GbW Settings", 0, 0, 0, 0, "GBWSETT", ""},               // 2
    {"Sleep time", default_sleepTime, 0, 300, 5, "SLEEPT", "min"},// 3
    {"Brightness", default_brightness, 1, 255, 1, "BRIGHTNESS", ""}, // 4
    {"LED max Brightness", default_led_brightness, 0, 100, 1, "LEDPRCT", "%"}, // 5
    {"Invert scrolling", 0, 0, 1, 1, "SCROLL", ""},            // 6
    {"Max RPM", default_maxRPM, absolute_min_rpm, absolute_max_rpm, rpm_scalar, "MAXRPM", "rpm"}, // 7
    {"Min RPM", default_minRPM, absolute_min_rpm, 500, rpm_scalar, "MINRPM", "rpm"},              // 8
    {"Motor torque", default_motor_torque, 1, 300, 1, "MOTORTORQ", "%"},               // 9
    {"Motor ramp", default_motor_ramp, 0, 12, 1, "MOTORRMP", "lvl"}, //10
    {"Calibrate", 0, 0 ,0, 0, "CALIBRATE", ""},           // 11
    {"Reset default", 0, 0, 1, 1, "RSTALL", ""},
};
#endif
#ifdef RT_DRIVE
menuEntry Menu1[NUM_MENU1_ITEMS] = {
    {"EXIT MENU", 0, 0, 0, 0, "EXITMENU", ""},                 // 0
    {"Purge Settings", 0, 0, 0, 0, "PURGESETT", ""},           // 1
    {"GbW Settings", 0, 0, 0, 0, "GBWSETT", ""},               // 2
    {"Sleep time", default_sleepTime, 0, 300, 5, "SLEEPT", "min"},// 3
    {"Brightness", default_brightness, 1, 255, 1, "BRIGHTNESS", ""}, // 4
    {"LED max Brightness", default_led_brightness, 0, 100, 1, "LEDPRCT", "%"}, // 5
    {"Invert scrolling", 0, 0, 1, 1, "SCROLL", ""},            // 6
    {"Max RPM", default_maxRPM, absolute_min_rpm, absolute_max_rpm, rpm_scalar, "MAXRPM", "rpm"}, // 7
    {"Min RPM", default_minRPM, absolute_min_rpm, 500, rpm_scalar, "MINRPM", "rpm"},              // 8
    {"Motor torque", default_motor_torque, 1, 300, 1, "MOTORTORQ", "%"},               // 9
    {"Calibrate", 0, 0 ,0, 0, "CALIBRATE", ""},           // 11
    {"Reset default", 0, 0, 1, 1, "RSTALL", ""},
};
#endif

menuEntry Menu2[NUM_MENU2_ITEMS] = {
    {"BACK", 0, 0, 0, 0, "RETURN2", ""},                                           // 0  RETURN_FROM_PURGE
    {"Auto purge", default_autoPurgeEnabled, 0, 1, 1, "AUTOPURGE", ""},    // 1  AUTO_PURGE_ENABLED
    {"Purge /w button", default_buttonPurge, 0, 1, 1, "PURGEBTN", ""},             // 2  SETBUTTONPURGE
    {"Purge forward RPM", default_purgeForwardRPM, absolute_min_rpm, absolute_max_rpm, rpm_scalar, "PURGEFWRPM", "rpm" },  // 3  SETPURGERPM
    {"Reverse rotation", default_reverseRotation, absolute_min_rpm, absolute_max_rpm, rpm_scalar, "RVRSRPM", "rpm"},            // 4  SETPURGEREVERSE
    {"Purge delay", default_purgeDelay, 100, 10000, 50, "PURGEDEL", "ms"},           // 5  SETPURGEDELAY
    {"Purge duration", default_purgeDuration, 500, 5000, 100, "PURGEDUR", "ms"},     // 6  SETPURGETIME
    {"Purge 0rpm time", default_purge_off_time, 0, 5000, 10, "PURGEOFFT", "ms"},     // 7  SETPURGEOFFTIME
    {"Purge stabilize time", default_purgeStabilTime, 100, 5000, 50, "PURGESTABILT" , "ms"}, // 8  SETPURGESTABILTIME
    {"Purge frames HIGH", default_purgeFramesHigh, 2, 20, 1, "PURGEFRH", ""},      // 9  SETPURGEFRAMESHIGH
    {"Purge frames LOW", default_purgeFramesLow, 2, 20, 1, "PURGEFRL", ""},        // 10 SETPURGEFRAMESLOW
    {"Purge Scalar HIGH", default_purgePrctHigh, 101, 200, 1, "PURGESCLRH", "%"},   // 11 SETPURGEPRCTHIGH
    {"Purge Scalar LOW", default_purgePrctLow, 101, 200, 1, "PURGESCLRL", "%"},     // 12 SETPURGEPRCTLOW
    {"Auto off time", default_auto_off_time, 0, 300, 10, "OFFTIME", "s"},           // 13 AUTO_OFF_TIME
};

menuEntry Menu3[NUM_MENU3_ITEMS] = {
    {"BACK", 0, 0, 0, 0, "RETURN3", ""},                            // 0 RETURN_FROM_GBW
    {"GbW RPM", default_GBWRPM, 200, 1500, rpm_scalar, "GBWRPMSET", "rpm"}, // 1 GBW_RPM_SET
    {"GbW Slow RPM", default_slow_rpm, rpm_scalar, 500, rpm_scalar, "GBWSLOWRPM", "rpm"}, // 2 GBW_SLOW_RPM
    {"GbW Slow mg", default_slow_mg, 0, 6000, 100, "GBWSLOWT", "mg"}, // 3 GBW_SLOW_PHASE GRAMS
    {"Start delay", default_start_delay, 0, 1000, 50, "GBWSTARTDEL", "ms"}, // 4 GBW_BUTTON_DELAY
    {"SpeedModifier", default_speedModifier, 1, 32767, 100, "GBWSPEEDMOD", ""},     // 5 GBW_SPEEDMOD
    {"Time offset", default_time_offset, 10, 1000, 10, "TIMEOFFSET", "ms"},           // 6 GBW_OFFSET
    {"Save scale", 0, 0, 1, 1, "SCALESTORED", ""},                                  // 7 SAVE_SCALE
};

volatile bool newData = true; //This is new TORQUE data.

volatile uint8_t error = 0;
int16_t setRPM = default_setRPM;
uint32_t setWeight = default_setWeight;

unsigned long lastActivity = 0;

RTC_DATA_ATTR uint8_t rtc_bootFlag1 = 0;
RTC_DATA_ATTR bool modeGbW = false;
RTC_DATA_ATTR uint8_t rtc_state;
RTC_DATA_ATTR uint16_t rtc_setRPM;

bool ready_purge = false;

unsigned long lastLoopTime = 0;
int loopcount = 0;


void scaleTask(void *pvParameters) {
    scales_init(); // Run once at task start

    // if (scaleMutex == NULL) {
    //     Serial.println("Failed to create scaleMutex!");
    //     error = 5;
    // }
    while (1) {
        gbwVitals();
        vTaskDelay(10 / portTICK_PERIOD_MS);
    }
}

void setup() { 
    Serial.begin(115200);
    scaleMutex = xSemaphoreCreateMutex();
    if (scaleMutex == NULL) {
        #ifdef DEBUG 
            Serial.println("Failed to create mutex!");
        #endif
        error = 5;
    }
    #ifdef DEBUG
    delay(2000);
    Serial.println("Starting!");
    #else
    delay(250);
    #endif
    
    setCpuFrequencyMhz(80);

    if(rtc_bootFlag1 == true) { 
        sleep_release();
    }

    pdata_init(); //This sets state as well!
    Serial.println("pdata init");

    if(firstBootFlag == 1) { 
         pdata_write(0);
         Serial.println("Wrote all default values...");
    } else { 
        pdata_read(); 
        Serial.println("pdata read");
    }
    pdata_normalize();
    
    xTaskCreatePinnedToCore(
    scaleTask,         // Task function
    "ScaleTask",       // Name
    8192,              // Stack size (adjust as needed)
    NULL,              // Parameter
    1,                 // Priority
    NULL,              // Task handle
    0                  // Core 0 (use 1 for core 1)
    );

    #ifdef DEBUG
    Serial.print("Wakeup cause: ");
    Serial.println(esp_sleep_get_wakeup_cause());
    Serial.print("Reset reason: ");
    Serial.println(esp_reset_reason());
    #endif

    display_init();
    Serial.println("display init");
    io_init();
    comm_init();
    Serial.println("Comm init");
    motor_init();
    Serial.println("motor_init");
    vitals_init();
    lastActivity = millis();
}

void loop() { 
    doVitals();
    do_comm();
    do_io();
    sleepTimeCheck();
    update_display();
    

    if(state == SLEEPING){ 
        esp_task_wdt_deinit();
        ledAction(0);
        motorOff();
        display_off();
        motorSleep();
        sleep_init();
    }
    
    if(state == IDLE)
    { 
        motor_setRPM = 0;
    }

    if(state == IDLE_GBW) { 
        motor_setRPM = 0;
    }

    if(state == GRINDING)
    { 
        checkPurge();
    }

    if(state == PURGING) { 
        ledAction(1);
        do_purge();
    }

    if(state == GRINDING_GBW)
    { 
        do_gbw();
        lastActivity = millis();
    }

    if(state == MENU1)
    { 
        motor_setRPM = 0;
        //everything handled in do_io
    }

    if(state == MENU2) { 
        motor_setRPM = 0;
        //everything handled in do_io
    }

    if(state == MENU3) { 
        motor_setRPM = 0;
        //everything handled in do_io
    }

    if(state == CALIBRATING) { 
        ledAction(1);
        Calibrate();
        lastActivity = millis();
    }

   // newData = false;
}


void checkPurge() { 
    static uint8_t frameCounter = 0;
    static int16_t last_setRPM;
    static unsigned long startTime = 0;
    static unsigned long lastCall = 0;
    static float test_torque;
    static int16_t test_scalar;
    static int16_t purge_frames;

    //if last call was +1000ms ago, reset.
    if(lastCall + 500 < millis()) { 
        lastCall = millis();
        startTime = millis();
        ready_purge = false;
        frameCounter = 0;
    }

    if(commStatus != COMM_CONNECTED) { 
        state = IDLE;
        motor_setRPM = 0;
    } else motor_setRPM = setRPM;

    //Reset if the RPM is changed
    if(setRPM != last_setRPM) {
        last_setRPM = setRPM;
        frameCounter = 0;
        ready_purge = false;
        startTime = millis();
    }

    // Auto off after x time no grinding detected
    if(Menu2[AUTO_OFF_TIME].value > 0) {
        if(startTime + Menu2[AUTO_OFF_TIME].value*1000 < millis() && ready_purge == false) { 
            motor_setRPM = 0;
            state = IDLE;
            lastActivity = millis();
        }
    }

    //Auto purge sequence
    if(Menu2[AUTO_PURGE_ENABLED].value == true && startTime + Menu2[SETPURGESTABILTIME].value < millis() && lastActivity + 1000 < millis() && newData == true) 
    { 

    //the torque defined during calibration
      if(rpm_scalar != 0) test_torque = calibrateArray[((setRPM + absolute_min_rpm)/rpm_scalar)];
      #ifdef DEBUG_CALIB
        Serial.print("torque: "), Serial.print(motor_currentTorque), Serial.print(" test: "), Serial.println(test_torque);
      #endif
      if(setRPM > 500) { //High values
        test_scalar = Menu2[SETPURGEPRCTHIGH].value;
        purge_frames = Menu2[SETPURGEFRAMESHIGH].value;
      } else {          // low values
        test_scalar = Menu2[SETPURGEPRCTLOW].value;
        purge_frames = Menu2[SETPURGEFRAMESLOW].value;
      }

      ///if the actual torque is greater than the calibrated torque*scalar we count up frames (note only when newData = true)
      if(motor_currentTorque > (test_torque*test_scalar)/100.f) { 
        frameCounter++;
        #ifdef DEBUG_CALIB
          Serial.print("frame counter: "), Serial.println(frameCounter);
        #endif
      } else {  //If it's smaller, we set the frames to 0;
        frameCounter = 0;
      }

      // If we've made the threshold once, purge will commence after grinding. LastActivity stay millis() as long as we're grinding beans
      if(frameCounter >= purge_frames)  
      { 
        ready_purge = true;
        lastActivity = millis(); //Update the last known time we were grinding.. 
      }
      
      //If the frames have gone to 0; we are no longer grinding -> after purgedelay(7) we will commense the purge
      if(ready_purge == true && (lastActivity + Menu2[SETPURGEDELAY].value) < millis()) 
      { 
        #ifdef DEBUG_CALIB
        Serial.println("go purge");
        #endif
        disp_updateRequired = true;
        ready_purge = false;
        frameCounter = 0; //should already be 0 but ok.
        state = PURGING;
        }
    }
    lastCall = millis();
}

void do_purge() { 
    static unsigned long lastCall;
    static unsigned long startTime;
    static uint8_t phase;
    static uint8_t last_purge_phase; 
    uint16_t delayTime = Menu2[SETPURGEOFFTIME].value;

    // if its the first call in a while..
    if(lastCall + 500 < millis()) { 
        lastCall = millis();
        startTime = millis(); 
        phase = 0;
        last_purge_phase = 0xFF;
        #ifdef DEBUG
            Serial.println("Purge commence..");
        #endif
        if(Menu2[SETPURGERPM].value == 0 && Menu2[SETPURGEREVERSE].value == 0) state = IDLE;
    }
    
    //started <delayTime ago
    if(startTime + delayTime > millis()) { 
        if(delayTime > 0) motor_setRPM = 0; 
        phase = 1; 
    }

    // Time between delayTime and 500 + purgeTime 
    if(startTime + delayTime < millis() && startTime + delayTime + Menu2[SETPURGETIME].value > millis()) {
        motor_setRPM = Menu2[SETPURGERPM].value > Menu1[SETMAX].value? Menu1[SETMAX].value : Menu2[SETPURGERPM].value; 
        phase = 2;
    }

    //We're not doing reverse
    if(Menu2[SETPURGEREVERSE].value == false && startTime + delayTime + Menu2[SETPURGETIME].value < millis()) {
        motor_setRPM = 0;
        state = IDLE;
        disp_updateRequired = true;
        phase = 5;
    } else { 
        //were doing reverse, pause for 500ms 
        if(startTime + delayTime + Menu2[SETPURGETIME].value < millis() && startTime + 2*delayTime + Menu2[SETPURGETIME].value > millis()) { 
            motor_setRPM = 0;
            phase = 3;
        }
        //do another reverse purge for purge time
        if(startTime + 2*delayTime + Menu2[SETPURGETIME].value < millis() && startTime + 2*delayTime + 2*Menu2[SETPURGETIME].value > millis()) {
            motor_setRPM = (-1) * (Menu2[SETPURGEREVERSE].value > Menu1[SETMAX].value? Menu1[SETMAX].value : Menu2[SETPURGEREVERSE].value);
            phase = 4;
        }
        if(startTime + 2*delayTime + 2*Menu2[SETPURGETIME].value < millis()) { 
            phase = 5;
            motor_setRPM = 0;
            state = IDLE;
            disp_updateRequired = true;
        }
    }

    if(phase != last_purge_phase) { 
        Serial.println(phase);
        disp_updateRequired = true;
        last_purge_phase = phase;
        Serial.println(motor_setRPM);
    }

    lastCall = millis();
}


void vitals_init() { 
  esp_task_wdt_init(3, false);
  esp_task_wdt_add(NULL); // Add current task (loop task)
}


void sleep_init() { 
    delay(100); //Allow shit to pass
    digitalWrite(RS485RE, HIGH); // Low power state
    digitalWrite(RS485DE, LOW); 
    digitalWrite(DISP_BL, LOW);
    delay(1);

    // Set BTN as input with pullup
    //pinMode(BTN, INPUT_PULLUP);

    rtc_bootFlag1 = true;

    // --- Enable RTC GPIO hold for RE, DE, DISP_BL ---
    rtc_gpio_hold_en((gpio_num_t)RS485RE);
    rtc_gpio_hold_en((gpio_num_t)RS485DE);
    rtc_gpio_hold_en((gpio_num_t)DISP_BL);


    rtc_gpio_hold_dis((gpio_num_t)BTN); // Release hold just in case for wake btn
    rtc_gpio_init((gpio_num_t)BTN);
    rtc_gpio_set_direction((gpio_num_t)BTN, RTC_GPIO_MODE_INPUT_ONLY);
    rtc_gpio_pullup_en((gpio_num_t)BTN);

    // Configure EXT0 wakeup on BTN (GPIO 4), wake on LOW level (button press)
    esp_sleep_enable_ext0_wakeup(WAKE_BTN, 0); // 0 = wake on LOW

    #ifdef DEBUG
        Serial.println("Entering deep sleep, waiting for BTN press to wake up...");
        Serial.print("BTN: "); Serial.println(digitalRead(BTN));
    #endif

    // Flush serial before sleeping
    Serial.flush();

    // Enter deep sleep (will not return until reset/wakeup)
    esp_deep_sleep_start();
}

void sleep_release() { 
   // --- Release RTC GPIO hold for RE, DE, DISP_BL ---
    rtc_gpio_hold_dis((gpio_num_t)RS485RE);
    rtc_gpio_hold_dis((gpio_num_t)RS485DE);
    rtc_gpio_hold_dis((gpio_num_t)DISP_BL);

    // Disable EXT0 wakeup source (optional, for clarity)
    esp_sleep_disable_wakeup_source(ESP_SLEEP_WAKEUP_EXT0);
    rtc_bootFlag1 = false;
}


void doVitals() { 
    esp_task_wdt_reset();

    #ifdef DEBUG
    unsigned long currentMicros = micros(); // or use millis() for ms accuracy
    unsigned long looptime = currentMicros - lastLoopTime;
    lastLoopTime = currentMicros;

    if(looptime > 500) {
        Serial.print("Loop time: ");
        Serial.print(looptime);
        Serial.println(" us");
    }
    #endif
}


void sleepTimeCheck() { 
    if(Menu1[SETSLEEP].value == 0) return;
    if(state == GRINDING || state == GRINDING_GBW) return;

    if(lastActivity + (Menu1[SETSLEEP].value * 60000) < millis() && millis() > (Menu1[SETSLEEP].value * 60000)) { 
        rtc_state = state; // save last state
        state = SLEEPING;
        #ifdef DEBUG
            Serial.println("sleep!");
        #endif
    }
}

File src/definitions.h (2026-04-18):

// pin definitions and settings
#include <Arduino.h>
#pragma once

// CHOOSE ONE
#define RT_DRIVE
// #define JMC_DRIVE 

//DEBUG FLAGS 
// #define DEBUG
#define DEBUG_SCALE false
// #define DEBUG_COMM
// #define DEBUG_MOTORCONTROL
// #define DEBUG_CALIB
// #define DEBUG_GBW

//#define BUILD_ID (new build ID = resets all saved params)
#define BUILD_ID "0002"

// USER SETTINGS
#define absolute_min_rpm 0
#ifdef RT_DRIVE
#define absolute_max_rpm 3000
#else
#define absolute_max_rpm 2000
#endif

#define rpm_scalar 25
#define SIZEOFCALIBRATEARRAY (2*(absolute_max_rpm - absolute_min_rpm)/rpm_scalar)
#define LONGPRESS 500 //after Xms a long press is registered
#define DISP_REFRESH_RATE 50 //Hz

// COMM PINS
#define RS485_RXD 18 
#define RS485_TXD 17
#define RS485RE 15
#define RS485DE 16

// IO PINS
#define BTN 4
#define start_button_led 5
#define ENC_BTN 42
#define ENC_A 41
#define ENC_B 40

// SPI display PINS
#define DISP_SCL 10
#define DISP_SDA 11
#define DISP_RST 12
#define DISP_DC 13
#define DISP_CS 14
#define DISP_BL 21

//EX_SPI (unused but accessible in the board)
#define EXSPI_MOSI 35
#define EXSPI_MISO 37
#define EXSPI_CLK 36
#define EXPSI_CS 39

//EX I2C (unused but accessible)
#define EXSDA 8
#define EXSCL 9

// COMM SETTINGS
#define COMMINTERVAL 60 // comm interval during normal operation
#define COMM_DELAY_RECEIVE 50 //expect a respond 10ms after request send
#define COMM_DELAY_IDLE 1000
#define COMM_DELAY_SEND 60 //send every 50ms max 
#define DISCONNECTED_AFTER 10000 //after Xms of not receiving comms, disconnected error shows
#define SEND_RPM_EVERY 5 //send RPM every X frames

// These must be the same as below!
#define WAKE_BTN GPIO_NUM_4
#define WAKE_ENC_BTN GPIO_NUM_42
#define WAKE_ENC_A GPIO_NUM_41
#define WAKE_ENC_B GPIO_NUM_40
#define SLEEP_RE GPIO_NUM_15
#define SLEEP_DE GPIO_NUM_16

//Encoder ticks per physical tick
#define ENC_TOL 1

//led behaviour
#define fadeTime 2500
#define flashTime 250
#define fastFlashTime 150
#define fastestFlashTime 75

// defaults
#define default_sleepTime 120 //in s
#define CAL_TIME 2500 //calibration time minus 500ms of settling in
#define default_setRPM 1000
#define default_brightness 200
#define default_maxRPM 2000
#define default_minRPM 100
#define default_motor_torque 100
#define default_led_brightness 100

#define default_motor_ramp 1

#define default_setWeight 18000
#define default_max_weight 99900
#define default_min_weight 6000
#define default_GBWRPM 800
#define default_slow_mg 4500
#define default_slow_rpm 300
#define default_speedModifier 2500
#define default_start_delay 100
#define default_time_offset 150
#define default_auto_off_time 60

#define default_autoPurgeEnabled 1
#define default_buttonPurge 1
#define default_autoPurgeEnabled 1
#define default_auto_off_time 60

#ifdef RT_DRIVE
#define default_purgeFramesLow 5
#define default_purgeFramesHigh 3
#define default_purgePrctLow 125
#define default_purgePrctHigh 125
#endif
#ifdef JMC_DRIVE
#define default_purgeFramesLow 7
#define default_purgeFramesHigh 5
#define default_purgePrctLow 130
#define default_purgePrctHigh 130
#endif

#define default_purgeDuration 3000
#define default_purgeDelay 2000
#define default_purgeForwardRPM 2000
#define default_reverseRotation 0
#define default_purgeStabilTime 500
#define default_purge_off_time 1000

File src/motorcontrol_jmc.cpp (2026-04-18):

#include "definitions.h"

#ifdef JMC_DRIVE
#include "motorcontrol_jmc.h"
#include "main.h"
#include "pdata.h"
#include "comm.h"
#include "display.h"


int16_t motor_currentRPM = 0;
int16_t motor_currentTorque = 0;
uint16_t motor_currentStatus = 0;
int16_t motor_setRPM = 0;
uint16_t currentCal = 0;
RTC_DATA_ATTR uint8_t rtc_bootFlagMotor = 0;
int16_t commCounter = 0;

unsigned long lastCommSend;

COMM_STATUS commStatus = COMM_DISCONNECTED;
SYSTEM_STATUS currentStatus = MOTOR_NOT_CONNECTED;

int16_t calibrateArray[SIZEOFCALIBRATEARRAY] = {0};

int16_t reg_6040 = -1; //Control word

int16_t reg_0101 = -1; //mode torque = 2;
int16_t reg_0121 = -1; //stop torque %
int16_t reg_0102 = -1; //Rigidity source selection
int16_t reg_0103 = -1; //rigidity amount (0-31)

int16_t reg_0500 = -1; // torq command source = 1
int16_t reg_0501 = -1; // speed limit source = 1
int16_t reg_0502 = -1; // speed limit setpoint = RPM (uint)
int16_t reg_0503 = -1; // torque SET POINT (-300 to 300)
int16_t reg_0510 = -1; // internal fw torque limit (int 0-300)
int16_t reg_0511 = -1; // internal rv torque limit (int -300 - 0)

enum DriveStatus{
    SWITCH_ON_DISABLED,
    READY_TO_SWITCH_ON,
    SWITCHED_ON,
    OPERATION_ENABLED,
    FAULT,
    FAULT_REACTION_ACTIVE,
    QUICK_STOP_ACTIVE,
    UNKNOWN_STATUS
};

DriveStatus decodeStatusWord(uint16_t statusWord) {
    // Extract relevant bits (0-6) from the status word
    uint8_t stateBits = statusWord & 0x006F; // bitmask 0b0000000001101111 (0, 1, 2, 3, 5, and 6)

    switch (stateBits) {
        case 0x0000: // 0b0000000
            return SWITCH_ON_DISABLED;
        case 0x0021: // 0b0100001
            return READY_TO_SWITCH_ON;
        case 0x0023: // 0b0100011
            return SWITCHED_ON;
        case 0x0027: // 0b0100111
            return OPERATION_ENABLED;
        case 0x0008: // 0b0001000
            return FAULT;
        case 0x000F: // 0b0001111
            return FAULT_REACTION_ACTIVE;
        case 0x0007: // 0b0000111
            return QUICK_STOP_ACTIVE;
        default:
            return UNKNOWN_STATUS;
    }
}

SYSTEM_STATUS changeToStatus(DriveStatus decodedStatusWord) { 
    switch(decodedStatusWord) { 
      case SWITCH_ON_DISABLED: return MOTOR_NOT_READY;
      case READY_TO_SWITCH_ON: return MOTOR_NOT_READY;
      case SWITCHED_ON: return MOTOR_READY;
      case OPERATION_ENABLED: return MOTOR_ENABLED;
      case FAULT: return MOTOR_FAULT;
      case FAULT_REACTION_ACTIVE: return MOTOR_FAULT;
      case QUICK_STOP_ACTIVE: return MOTOR_FAULT;
      default: return MOTOR_INVALID;
    }
}

void motor_init() {
  motor_setRPM = 0;
  reg_6040 = -1; //Control word

  reg_0500 = -1; // torq command source = 1
  reg_0501 = -1; // speed limit source = 1
  reg_0502 = -1; // speed limit setpoint = RPM (uint)
  reg_0503 = -1; // torque SET POINT (-300 to 300)
  reg_0510 = -1; // internal fw torque limit (int 0-300)
  reg_0511 = -1; // internal rv torque limit (int -300 - 0)
  
  commStatus = COMM_DISCONNECTED;
  currentStatus = MOTOR_NOT_CONNECTED;
}

bool do_comm() { // can be called continously and will update all values. Returns true when new data packet is available.
    /* COMM TYPES
    0 = send RPM
    1 = read status word 0x6041
    2+ = READ STATUS, RPM, TORQUE (1300, 1301, 1302, 1303)
    */
  static unsigned long lastCommReceived;
  // static uint8_t lastCommType;
  static uint8_t nextCommType;
  static int16_t motor_lastSetRPM = -1;

  //Disconnect flow
  if(lastCommReceived + 4*COMM_DELAY_IDLE < millis() && lastCommReceived > 0) { 
    #ifndef DEBUG
      error = 2;
    #endif

    #ifdef DEBUG_MOTORCONTROL
      Serial.print("Have not received a message for: "), Serial.print(millis()-lastCommReceived), Serial.println("ms -> DISCONNECTED");
    #endif
    commStatus = COMM_DISCONNECTED;
    currentStatus = MOTOR_NOT_CONNECTED;
    disp_updateRequired = true;

    reg_6040 = -1; //Control word
    reg_0502 = -1; //speed
    reg_0503 = -1; //torque
  }

//Cannot establish connection 
  if(lastCommReceived == 0 && commStatus == COMM_DISCONNECTED && millis() > DISCONNECTED_AFTER) { 
    #ifndef DEBUG
      error = 1;
    #endif
    currentStatus = MOTOR_NOT_CONNECTED;
    disp_updateRequired = true;
  }

  //Unstable connection flow
  if(commStatus != COMM_DISCONNECTED && commCounter > 25 ) { 
    error = 4;
    motor_setRPM = 0;
    state = IDLE;
    disp_updateRequired = true;
  }

  // Motor stall flow
  int16_t torquePercent;
  if((Menu1[SETMOTORTORQUE].value) > 0) torquePercent = 10 * (motor_currentTorque / Menu1[SETMOTORTORQUE].value); //A value 
  else torquePercent = 0;
  if(motor_setRPM != 0 && torquePercent > 90 && abs(motor_currentRPM) < rpm_scalar) { 
    motor_setRPM = 0;
    state = IDLE; 
    error = 6;
  }

  // First communication when disconnected
  if(commStatus == COMM_DISCONNECTED) { 

    if(lastCommSend + COMM_DELAY_SEND > millis()) return false;

    if(writeConfirm(0x6040, 1)) { //This is blocking

      #ifdef DEBUG_MOTORCONTROL
        Serial.println("We're connected!.. ");
      #endif
      readReturn(0x1010, 2); //read magic byte setting MSB 
      // Check if magic byte is already set
      if(lastRead[0] != 0x6576 && lastRead[1] != 0x6173) { 
        if(!writeMultipleConfirm(0x1010, 2, 0x6576, 0x6173)) return false;  // magic byte "Save" to 0x1010 
        if(readReturn(0x2101, 1) != 2) error = 8;   //Confirm we've already written data or not.. to recognize a first boot event.

        int score = 0; 
        if(writeConfirm(0x2101, 2)) { reg_0101 = 2; score++; } //Set mode to torque control

        // Motor rigidity settings.. automatic mode with 0 gain and 2000 filter.
        if(writeConfirm(0x2102, 1)) { reg_0102 = 1; score++; } // MODE 1 - semi auto
        if(writeConfirm(0x2103, Menu1[SETMOTORRAMP].value)) { reg_0103 = Menu1[SETMOTORRAMP].value; score++; } //P103 set, this is set in the MENU

        if(writeConfirm(0x2121, 30)) { reg_0121 = 30;  score ++; } //This is the quickstop ramp down torque (currently not used i believe the way we use it)

        if(writeConfirm(0x2203, 0)) { score ++; } // velocity feedforward gain
        if(writeConfirm(0x2204, 2000)) { score ++; } // 
        // VALUES ABOVE
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

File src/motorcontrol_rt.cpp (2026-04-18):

#include "definitions.h"
#ifdef RT_DRIVE
#include "motorcontrol_rt.h"
#include "main.h"
#include "pdata.h"
#include "comm.h"
#include "display.h"

int16_t motor_currentRPM = 0;
int16_t motor_currentTorque = 0;
uint16_t motor_currentStatus = 0;
int16_t motor_setRPM = 0;
uint16_t currentCal = 0;
RTC_DATA_ATTR uint8_t rtc_bootFlagMotor = 0;
int16_t commCounter = 0;

int16_t calibrateArray[SIZEOFCALIBRATEARRAY] = {0};

COMM_STATUS commStatus = COMM_DISCONNECTED;
SYSTEM_STATUS currentStatus = MOTOR_NOT_CONNECTED;

// Actual register mirrors (reflect what the controller has confirmed)
int16_t reg_201 = -1; //enable disable drive (0 / 1)
int16_t reg_503 = 0; //Set torque;
int16_t reg_514 = -1; //Speed limit forward (pos value)
int16_t reg_515 = -1; //Speed limit reverse (pos value)
int16_t reg_525 = -1; //JOG disable / enable (0 / 1)
int16_t reg_701 = -1;

//Only necessary for sending multiple writes
int16_t pending_reg_514 = 0xFFFF;
int16_t pending_reg_515 = 0xFFFF;

/* Important motor parameters for RT, note this is decimal, and should be communicated in HEX (below is bin)
0022 -> motor rated torque

0100 -> control mode (3 = torque mode)

1300 -> running status
1301 -> current RPM
1303 -> motor torque
1353 -> internal fault code -> no clue what is what ??

*/

void motor_init() {
  motor_setRPM = 0;
  reg_201 = -1;
  reg_503 = 0;
  reg_514 = -1;
  reg_515 = -1;
  reg_525 = -1;
  commStatus = COMM_DISCONNECTED;
  currentStatus = MOTOR_NOT_CONNECTED;
}

bool do_comm() { // can be called continously and will update all values. Returns true when new data packet is available.
    /* COMM TYPES
    0 = send RPM
    1+ = READ STATUS, RPM, TORQUE (1300, 1301, 1302, 1303)
    */
  static unsigned long lastCommSend;
  static unsigned long lastCommReceived;
  static uint8_t lastCommType;
  static uint8_t nextCommType;
  static int16_t motor_lastSetRPM;

  //Disconnect flow
  if(lastCommReceived + 2*COMM_DELAY_IDLE < millis() && lastCommReceived > 0) { 
    #ifndef DEBUG
      error = 2;
    #endif
    commStatus = COMM_DISCONNECTED;
    currentStatus = MOTOR_NOT_CONNECTED;
    disp_updateRequired = true;
    reg_201 = -1;
    reg_514 = -1;
    reg_515 = -1;
    reg_525 = -1;
    reg_201 = -1;
  }

  if(lastCommReceived == 0 && commStatus == COMM_DISCONNECTED && millis() > DISCONNECTED_AFTER) { 
    #ifndef DEBUG
      error = 1;
    #endif
    currentStatus = MOTOR_NOT_CONNECTED;
    disp_updateRequired = true;
  }

  //Unstable connection flow
  if(commStatus != COMM_DISCONNECTED && commCounter > 25 ) { 
    error = 4;
    motor_setRPM = 0;
    state = IDLE;
    disp_updateRequired = true;
  }

  // Motor stall flow
  int16_t torquePercent;
  if((Menu1[SETMOTORTORQUE].value*10) > 0) torquePercent = (1000 * motor_currentTorque / (Menu1[SETMOTORTORQUE].value*10)); //A value 
  else torquePercent = 0;
  if(motor_setRPM != 0 && torquePercent > 90 && abs(motor_currentRPM) < rpm_scalar) { 
    motor_setRPM = 0;
    state = IDLE; 
    error = 6;
  }

  // First communication when disconnected
  if(commStatus == COMM_DISCONNECTED) { 
    if(writeMultipleConfirm(514, 2, 0, 0)) {
      #ifdef DEBUG_MOTORCONTROL
        Serial.println("We're connected!");
      #endif
      int score = 0;
      Serial.println("701: "), Serial.println(readReturn(701, 1));
      //if(writeConfirm(701, Menu1[SETMOTORRAMP].value)) { reg_701 = Menu1[SETMOTORRAMP].value ; score++; } 

      reg_514 = 0;
      reg_515 = 0;
      reg_525 = -1;
      reg_201 = -1;
      lastCommReceived = millis();
      nextCommType = 0;
      commStatus = COMM_CONNECTED;
      currentStatus = MOTOR_NOT_READY;
      commCounter = 0;
    } 
    lastCommSend = millis();
    return false;
  }

  // The only FAST & blocking service we're offering!
  if(motor_setRPM == 0 && motor_lastSetRPM != 0) { 
    if(reg_514 != 0) { 
      if(writeMultipleConfirm(514, 2, 0, 0)) { 
        reg_514 = 0; 
        reg_515 = 0; 
      }
    }
    motor_lastSetRPM = motor_setRPM;
    nextCommType = 0;
    return false;
  }

  // >>>>>>>> RECEIVE <<<<<<<< 
  int16_t received = receive();
  if(received > 0) {
    #ifdef DEBUG_MOTORCONTROL
      Serial.print("received!: "), Serial.println(received);
      Serial.print("Commcounter: "), Serial.println(commCounter);
      Serial.print("next comm type: "), Serial.println(nextCommType); 
    #endif
    // ERROR HANDLING 
    if(error == 2 || error == 1) { 
      error = 0;
      disp_updateRequired = true;
    }

    // DEBUG 
    #ifdef DEBUG_MOTORCONTROL
      if(lastRequestType == 0 || lastRequestType > 200) {
        Serial.println("received succesfull!");
        Serial.print("reg 201: "), Serial.println(reg_201);
        Serial.print("reg 503: "), Serial.println(reg_503);
        Serial.print("reg 514: "), Serial.println(reg_514);
        Serial.print("reg 515: "), Serial.println(reg_515);
        Serial.print("reg 525: "), Serial.println(reg_525);
      }
    #endif

    // STATUS UPDATING
    commStatus = COMM_CONNECTED;
    if(currentStatus == MOTOR_NOT_CONNECTED) currentStatus = MOTOR_NOT_READY;
    lastCommReceived = millis(); 

    // >>>>>> SEND SINGLE WRITE
    if(lastRequestType == 0) {  
      switch(received) {
        case 201: { reg_201 = lastRead[0]; break; }
        case 503: { reg_503 = lastRead[0]; break; }
        case 514: { reg_514 = lastRead[0]; break; }
        case 515: { reg_515 = lastRead[0]; break; }
        case 525: { reg_525 = lastRead[0]; break; }
      }
    }

    // >>>>> DATA REQUESTS (1300 && 0x6041)
    if(lastRequestType > 100 && lastRequestType < 200) { 
      if(received == 1300 && lastRequestType == 104) { // A request for status, speed & torque
          motor_currentStatus = lastRead[0];
          motor_currentRPM = lastRead[1];
          //skip 2 = setRPM
          motor_currentTorque = lastRead[3];
          newData = true;
          #ifdef DEBUG_MOTORCONTROL
            Serial.println("Newdata!");
          #endif
          if(motor_currentStatus == 0) currentStatus = MOTOR_READY;
          if(motor_currentStatus == 1) currentStatus = MOTOR_ENABLED;
      }
    }

    // >>>>> Send multiple writes
    if(lastRequestType > 200 && lastRequestType < 205) { //A SEND of max 4 writes
      if(received == 514 && lastRequestType == 202) { 
        reg_514 = pending_reg_514;
        reg_515 = pending_reg_515;
      }
    }
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

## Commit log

2025-07-04 Update after testing with PCB
    first update after testing with PCB.
    Most except motor communication has been tested and seems proper.
2025-07-04 Added PCB files REV0A
    [BOM_SG98_2025-06-16.csv, PCB_SG98_2025-06-18.dxf, PickAndPlace_PCB_SG98_2025-06-16.csv]
2025-08-06 Update to various parts
    - Made comms more robust
    - added more user editable settings regarding UI.
    - First testing draft for JMC motor
2025-09-07 V1.0
    JMC and RT drive fully working.
    JMC drive currently running in Speed mode, adjustable accel & decel but no torque control.
    RT adjustable torque control, but ramp is not adjustable.
2025-09-15 Update v1.1
    Major change on JMC - move from Speed mode to Torque mode, and adding a motor torque setting and motor rigidity setting which determines motor behaviour.
2025-10-10 Support files
    [LL SideBox V5 JMC v0.3mf, LL SideBox V5 RT v0.3mf]
2025-10-10 Update with RESET option
    [display.cpp, gbw.cpp, io.cpp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]
2025-10-19 Adding all 3DP files
    [Cup+holder+V2++3mf.3mf, Hopper+V2+3mf.3mf]
2026-04-18 Increase ScaleTask stack size to 8192 bytes for NimBLE stability
    [main.cpp]
2026-04-18 fix: resolve motor connection drops in GbW mode
    [motorcontrol_jmc.cpp]
